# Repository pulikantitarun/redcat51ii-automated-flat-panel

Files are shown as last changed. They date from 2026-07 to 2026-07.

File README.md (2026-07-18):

# RedCat 51 II Automated Flat Panel — Revision C

A servo-driven flat panel / dust cover for the William Optics RedCat 51 II,
commanded from an ASIAIR dew-heater port.

---

## Read this before anything else

Rev B was described as fabrication-ready. It was not. It had a firmware loop
that would hold a stalled 20 kg servo at ~2.7 A indefinitely, an ASIAIR input
that could not physically work, four disconnected bodies in an STL, and not one
copper zone on a 4-layer board carrying two switching regulators. It also had
"0 DRC violations", which is exactly why that number should never have
reassured anyone.

**Rev C is not fabrication-ready either.** It is *correct as far as it has been
checked*, and it now tells you loudly where the checking stops. The difference
between Rev B and Rev C is not that Rev C is finished — it is that Rev C
asserts its own assumptions instead of hiding them.

### Status by subsystem

| Subsystem | State | Verified how |
|---|---|---|
| Mechanical | **Verified** | 19 numeric clearance assertions pass; all 10 meshes single-body and watertight; assembly STEP builds in one shared coordinate frame |
| Firmware | **Reviewed, not run** | No ESP32 toolchain was available; not compiled, not flashed, not measured |
| PCB netlist & stackup | **Asserted** | 36 netlist/stackup assertions pass (`verify_board.py`) |
| PCB routing | **Not done** | Signals unrouted; needs the freerouting round-trip + manual widening |
| PCB schematic / ERC | **Does not exist** | ← the single biggest remaining risk |

---

## The four numbers you must measure

Everything in the mechanical model derives from these. Each has a cheap coupon
to check it. Print the coupons first — they are minutes of filament, and every
one of them protects hours of it.

| # | Parameter | Default | Coupon | What happens if it's wrong |
|---|---|---|---|---|
| 1 | `SCOPE_DIAMETER` | 80.0 mm | `01-diameter-fit-gauge` | Clamp won't fit, or won't grip |
| 2 | `SERVO_SHAFT_OFFSET` | 10.0 mm | `09-servo-shaft-gauge` | Closed panel sits 7–13 mm off the optical axis |
| 3 | `SERVO_EAR_TO_TOP` | 10.0 mm | `09-servo-shaft-gauge` | Tray fouls the servo, or floats above the horn |
| 4 | `DC_JACK_AXIS_Z` | 4.7 mm | `10-connector-wall-coupon` | Barrel plugs don't line up with their holes |

The 80 mm default deserves special suspicion: William Optics quote
"228 × 80 mm with the retracted dew shield". That is a *marketing envelope
figure*, not a measurement of the surface this clamp grips. Measure it.

**A fifth measurement, electrical, is just as important — see below.**

---

## The ASIAIR ground question — measure this before you build the board

Rev C replaces Rev B's opto-isolator with a plain resistive divider into an
ADC. That is the right call (see *Firmware* below), but it costs you the
galvanic isolation, and it therefore **assumes the ASIAIR switches the HIGH
side of its dew ports** — i.e. that the port's negative terminal is common with
the ASIAIR's own 12 V input negative.

All the indirect evidence says it does. People run grounded 12 V→5 V buck
converters off these ports, feeding USB devices that plug straight back into
the ASIAIR, which would be a dead short across a low-side switch. And a
multimeter inline reads ~6 V average at the 50 % slider position, which is what
a high-side switch with a grounded return looks like.

But I have not put a meter on one, and neither should you take my word for it:

> **Check continuity between the ASIAIR dew port's barrel SLEEVE and the
> ASIAIR's power input NEGATIVE terminal.**
> - Near 0 Ω → common ground. Build as drawn.
> - Anything else → **stop.** Do not fit R19. The front end needs rethinking
>   and I'd want to see the measurement before redesigning it.

Thirty seconds with a multimeter, before you spend money.

---

## What changed, and why

### Mechanical — `mechanical/generate_parts.py`

Rev B built every part in its own private coordinate system and never
assembled them. That is how all of the following escaped:

- **The enclosure was built centred on z=0 but every cut-out was placed as if
  the floor were z=0.** The connector openings sat ~14 mm too high and breached
  the top rim.
- **The four PCB standoffs floated in mid-air.** They were extruded z=0..7
  while the cavity floor sat at z=−11.5. The STL contained five disconnected
  bodies. A slicer would have printed four little pillars lying on the bed.
- **The tray pivot assumed the servo's output shaft is at the centre of its
  body.** It is not — a standard 40 mm servo has its shaft offset ~10 mm. The
  closed panel would have sat 7–13 mm off the optical axis.
- **The servo platform met the clamp with a ~1 mm sliver of overlap**, no
  gussets, no fillets.
- **The limit-switch bracket's base and upright met on a single plane with zero
  overlap** — a degenerate union that exports a non-watertight mesh.

Rev C builds every part in **one shared scope coordinate frame**, asserts the
clearances numerically, and exports an assembly STEP so the next mistake of
this class is visible instead of latent.

Also new in Rev C:

- **The lid is screwed, not friction-fit.** This box lives outdoors, upside
  down, in dew, on a moving mount. Four M3 corner bosses with heat-set inserts,
  outboard of the cavity so they cost no internal volume. The lid's spigot lip
  is notched around them.
- **Strap ears.** The box now has somewhere to attach. Thread a hook-and-loop
  strap down through one ear, under the dovetail bar, up through the other.
  **Hang it off the dovetail, not the dew shield** — the shield is a slip joint
  and it will happily let go of an 80 mm tube.

Run it:

```bash
cd mechanical && python3 generate_parts.py
```

It prints 19 clearance assertions and exits non-zero if any fail. All 10 STLs
are single-body and watertight; verify with the trimesh snippet in
`docs/verification.md` if you want to confirm that yourself rather than trust
this file.

### Firmware — `firmware/redcat_flat_panel/`

**1. The ASIAIR input is no longer a duty-cycle measurement.** Rev B called
`pulseIn()` on an opto to recover the ASIAIR's PWM duty. That cannot work on an
ASIAIR Plus:

- The Plus **capacitively filters** its power outputs. Rev B's opto drew ~4.9 mA
  through a 2.2 k resistor — nowhere near enough to discharge that filter inside
  a 20 ms period. The port never left 12 V, so **every slider position read as
  100 %**.
- The port period is 20 ms and Rev B's `pulseIn` timeout was 30 ms. A missed
  edge returned 0 → "command 0" → **the flap flings open in the middle of a
  flat sequence.**

Rev C stops fighting the filter and uses it: it loads the port properly (470 Ω,
1 W) and measures the **average voltage** on ADC1. The same filtering that
destroys duty-sniffing is what makes the average track the slider — 50 % reads
~6 V, 100 % reads ~12 V.

**2. A failed move no longer retries forever.** Rev B's `moveFlap()` set
`isClosed = false` on timeout *regardless of which direction it was moving*. So
a jammed flap reported "open", the next loop pass commanded "close" again ~50 ms
later, and it did that forever — holding a stalled DS3218 at ~2.7 A until
something gave up. Rev C latches a **FAULT** after 3 bounded attempts, detaches
the servo between every attempt, and refuses to move again until a human holds
the button for 2 s.

**3. The move is non-blocking.** Rev B blocked inside `moveFlap()` for up to 5 s
with the button dead.

**4. The ASIAIR boot transient is handled.** Every ASIAIR drives all power ports
to FULL for a few seconds at boot before loading its saved settings. Rev B read
that as "100 % — close and light up". Rev C ignores the input until it has been
stable for 6 s.

**5. Thresholds no longer collide.** Rev B used 3 % / 8 % boundaries when the
ASIAIR slider's minimum non-zero step is **5 %**, with no hysteresis — a reading
sitting on a boundary would dither the flap. Rev C works in **port volts**
(what the board can actually observe) with 0.3 V of hysteresis at every
boundary.

**6. It does not move on boot.** Rev B blindly drove to OPEN in `setup()`,
slamming the flap against its stop every time the ASIAIR's 12 V rail browned out
on a mount slew. Rev C adopts whatever state the limit switches report.

> **This firmware has not been compiled.** There was no ESP32 toolchain
> available in the environment it was written in. Expect to fix at least a
> typo. Read it before you flash it.

**Calibration:** if the panel lights at the wrong slider position, put a
voltmeter on the ASIAIR port at 100 %, set `PORT_FULL_V` to what you actually
read (a "12 V" supply is usually 12.2–13.8 V), and reflash. Nothing else needs
touching.

### PCB — `pcb/source/generate_board.py`

**1. Copper zones.** Rev B had **none** — zero zones, zero G36 fill records in
every gerber, on a 4-layer board with a 4 A switcher. GND was 129 individual
tracks totalling ~500 mm.

Rev C makes **both inner layers solid GND** and pours GND on F.Cu/B.Cu, with
124 stitching vias. Every switching node now has an unbroken return directly
beneath it.

Why two ground planes rather than GND + a split power plane: the Rev B
placement interleaves +12V, +6V and +3V3 across the same X range, so **no
rectangular power split is possible without re-placing every part**. SIG/GND/
GND/SIG is the correct stackup for *this* placement, costs nothing, spreads
regulator heat, and removes any chance of a return path crossing a plane split.
+12V and +6V remain wide tracks, as they were in Rev B — but Rev B's actual
defect was that *GND* had no plane, and that is now fixed twice over.

**2. USBLC6-2SC6 net assignment fixed.** Pins 1 and 6 are one internal node;
3 and 4 are another. Rev B straddled the 22 Ω series resistors across them,
**shorting both out**. DRC was perfectly happy.

**3. J3 re-pinned to GND / V+ / SIG.** Rev B wired 6V / GND / SIG, which lands
6 V on the servo lead's black wire whichever way round you plug it in.

**4. Q1's gate is no longer tied straight to GND.** Vgs was the full rail. While
D1 clamps a surge it would have exceeded the AO4407A's ±20 V limit and destroyed
the FET. Now 100 k to GND plus a 10 V zener gate-to-source.

**5. D1 SMBJ18A → SMBJ14A.** An 18 V standoff part clamps at ~29 V — above the
AO4407A's 30 V Vds rating with no margin. 14 V standoff clamps at ~23 V.

**6. F1 3 A → 4 A.** A 3 A PTC derates to ~2.4 A hold in a sealed box, below the
DS3218's 2.7 A stall. It would have nuisance-tripped mid-sequence.

**7. Buck input capacitance raised.** A 10 µF 25 V 0805 X5R at 12 V DC bias
derates to ~4–5 µF; that was the *entire* input reservoir for a 4 A regulator.
Now 2× 10 µF 1210 plus 100 nF per regulator.

**8. Minimum drill 0.2 → 0.3 mm**, above every fab's surcharge threshold.

Run it:

```bash
cd pcb/source
python3 generate_board.py     # places parts, nets, zones, stitching vias
python3 verify_board.py       # 36 netlist/stackup assertions
python3 generate_bom.py       # BOM generated FROM the board, so it can't drift
```

---

## What is still missing — the honest list

1. **There is no schematic, and therefore there has been no ERC.** This is the
   biggest risk in the project. A DRC pass against a hand-typed netlist only
   proves the copper matches what you typed; it cannot tell you the netlist
   itself is wrong. That is *precisely* how the USBLC6 short and the servo
   header pinout survived Rev B's "0 DRC violations". `verify_board.py` raises
   the floor but it is not ERC. **Draw the schematic before you spend money.**

2. **Signals are not routed.** `generate_board.py` emits placement, nets and
   pours. The Rev B flow still applies — `export_dsn.py` → freerouting →
   `import_ses.py` → manually widen the +12 V / +6 V paths — **except that GND
   must no longer be handed to the autorouter.** It lives on the planes now.

3. **Zones are defined but not filled in the saved file.** pcbnew's `ZONE_FILLER`
   segfaults when driven from standalone Python on KiCad 7 (verified: it does so
   even under a wx app and a virtual X display). The zones are defined, netted
   and layered correctly — but **KiCad plots gerbers from the *stored* fill.**
   Open the board in pcbnew, press **B**, run DRC, *then* plot. Plotting without
   filling gives you planeless gerbers — the exact Rev B failure, wearing a
   Rev C label.

4. **The firmware has never been compiled or run.**

5. **The board was generated here against KiCad 7**, because that is what was
   installable; you built Rev B on KiCad 10. The script is version-tolerant now
   (it searches for the footprint libraries instead of hard-coding
   `C:\Users\tarun\...`, and accepts alternate footprint names), but **re-run it
   on your KiCad 10** and use that output. One visible symptom: the BOM here
   lists `SW_Push_1P1T_NO_CK_KMR2` for SW1–3 because KiCad 7's library lacks the
   TL3301; KiCad 10 will pick the TL3301 as intended.

6. **The 6 V rail is still track-routed at up to 2.7 A.** Widen it by hand after
   routing. 3 mm on 1 oz copper is roughly 3 A.

---

## Suggested order of work

1. Multimeter on the ASIAIR dew port ground. **30 seconds. Do it first.**
2. Print `01`, `09`, `10`. Measure the four parameters. Update the constants.
3. Re-run `generate_parts.py`. Confirm 19/19 assertions still pass.
4. Print `02`–`08`. Assemble dry, no electronics.
5. Draw the schematic in KiCad from `generate_board.py`. Run ERC. **Expect it to
   find something.**
6. Route, fill, DRC, then fab.
7. Bench the firmware on the bare board with a current-limited supply and a
   servo you don't love, before it ever goes near the RedCat.

---

## Layout

```
mechanical/
  generate_parts.py          one coordinate frame, 19 assertions, 10 parts
  00-ASSEMBLY.step           everything placed in the scope frame
  01..10-*.stl/.step         printable parts + verification coupons
firmware/
  redcat_flat_panel/redcat_flat_panel.ino
pcb/
  BOM_RevC.csv               generated from the board
  source/
    generate_board.py        placement, nets, zones, stitching
    verify_board.py          36 netlist/stackup assertions
    generate_bom.py
```

## License

Copyright (C) 2026 pulikantitarun

This project - the mechanical design files, firmware, PCB design, and documentation - is licensed under the **GNU Affero General Public License, version 3 or later (AGPL-3.0-or-later)**. See [LICENSE](LICENSE) for the full text.

You are free to use, study, share, and modify this work, including as forks. In return, the copyleft terms require that if you distribute a modified version - or run a modified version to offer a service over a network - you make your modified source available under this same license. Forks and derivatives must remain AGPL-3.0.

Note on scope: AGPL is a software license. It fits the firmware and the generator scripts cleanly; the mechanical CAD/STL and PCB design files are released under it here as copyrightable design works. If you later want a copyleft written specifically for physical hardware, CERN-OHL-S is the usual companion, but AGPL across the whole repository is a common, valid choice and satisfies the goal that forks stay open. This paragraph is not legal advice.

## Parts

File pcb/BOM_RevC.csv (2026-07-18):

Comment | Designator | Footprint | Quantity
1uF | C1 | C_0603_1608Metric | 1
470uF 25V | C2 | CP_Elec_10x10.5 | 1
100nF | C3,C8,C13,C15,C16,C17 | C_0603_1608Metric | 6
10uF 25V | C4B,C4,C9 | C_1210_3225Metric | 3
22uF 10V | C5,C6,C10,C11 | C_0805_2012Metric | 4
470uF 10V | C7 | CP_Elec_8x10.5 | 1
10uF | C12,C14 | C_0805_2012Metric | 2
SMBJ14A | D1 | D_SMB | 1
MMSZ5226B 3V3 | D2 | D_SOD-123 | 1
MMSZ5240B 10V | D3 | D_SOD-123 | 1
4A 16V PTC | F1 | Fuse_1812_4532Metric | 1
MAIN 12V DC5521 | J1 | BarrelJack_CUI_PJ-102AH_Horizontal | 1
ASIAIR PWM DC5521 | J2 | BarrelJack_CUI_PJ-102AH_Horizontal | 1
SERVO GND 6V SIG | J3 | PinHeader_1x03_P2.54mm_Vertical | 1
LED PANEL | J4 | JST_XH_B2B-XH-A_1x02_P2.50mm_Vertical | 1
OPEN LIMIT | J5 | JST_XH_B2B-XH-A_1x02_P2.50mm_Vertical | 1
CLOSED LIMIT | J6 | JST_XH_B2B-XH-A_1x02_P2.50mm_Vertical | 1
EXT MANUAL | J7 | JST_XH_B2B-XH-A_1x02_P2.50mm_Vertical | 1
USB-C PROGRAM | J8 | USB_C_Receptacle_GCT_USB4105-xx-A_16P_TopMnt_Horizontal | 1
3.3uH 6.5A | L1 | L_6.3x6.3_H3 | 1
4.7uH 3A | L2 | L_6.3x6.3_H3 | 1
STATUS BLUE | LED1 | LED_0603_1608Metric | 1
POWER GREEN | LED2 | LED_0603_1608Metric | 1
AO4407A | Q1 | SO-8_3.9x4.9mm_P1.27mm | 1
AO3400A | Q2 | SOT-23 | 1
5.1k | R1,R2 | R_0603_1608Metric | 2
22R | R3,R4 | R_0603_1608Metric | 2
10k | R5,R6,R10,R12,R13,R14,R15 | R_0603_1608Metric | 7
64.9k 1% | R7 | R_0603_1608Metric | 1
10k 1% | R8 | R_0603_1608Metric | 1
470R 1W | R9 | R_2512_6332Metric | 1
100R | R11 | R_0603_1608Metric | 1
1k | R16,R17 | R_0603_1608Metric | 2
100k | R18,R21 | R_0603_1608Metric | 2
0R | R19 | R_1206_3216Metric | 1
3k3 | R20 | R_0603_1608Metric | 1
RESET | SW1 | SW_Push_1P1T_NO_CK_KMR2 | 1
BOOT | SW2 | SW_Push_1P1T_NO_CK_KMR2 | 1
MANUAL | SW3 | SW_Push_1P1T_NO_CK_KMR2 | 1
ESP32-S3-WROOM-1-N8R8 | U1 | ESP32-S3-WROOM-1 | 1
USBLC6-2SC6 | U2 | SOT-23-6 | 1
AP62401WU-7 | U3 | TSOT-23-6 | 1
AP63203WU-7 | U4 | TSOT-23-6 | 1

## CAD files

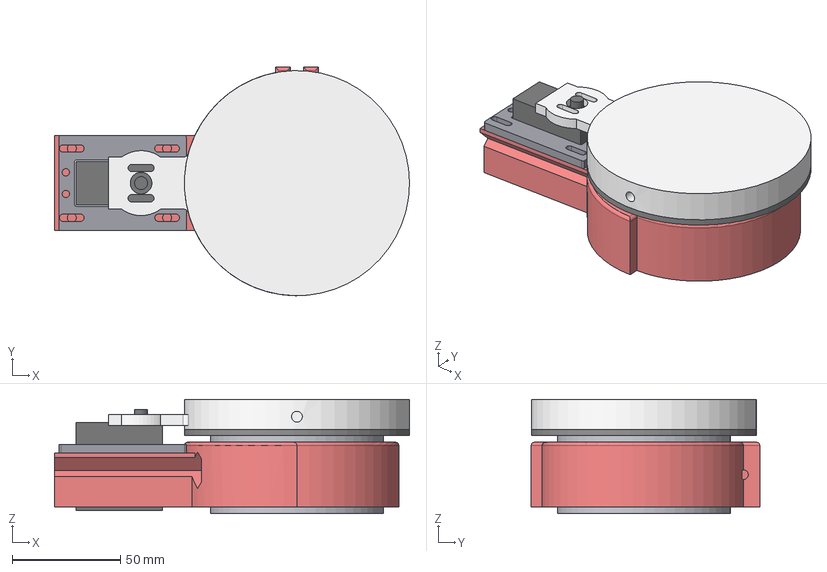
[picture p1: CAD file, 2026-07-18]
mechanical/00-ASSEMBLY.step
164.0 x 105.6 x 52.8 mm
clamp
servo_plate
tray
retainer
servo_envelope
dew_shield_envelope

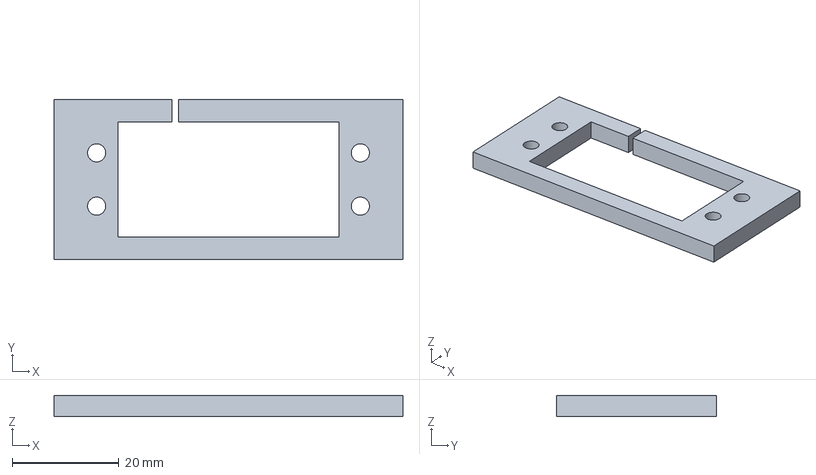
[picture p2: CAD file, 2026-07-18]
mechanical/09-servo-shaft-gauge.step
65.5 x 30.0 x 4.00 mm

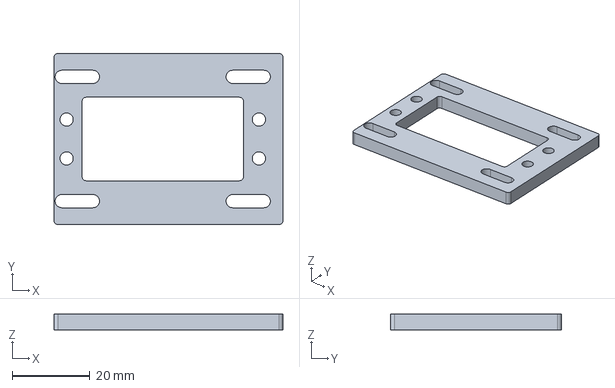
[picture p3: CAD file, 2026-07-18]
mechanical/03-ds3218-servo-plate.step
59.0 x 44.0 x 4.00 mm

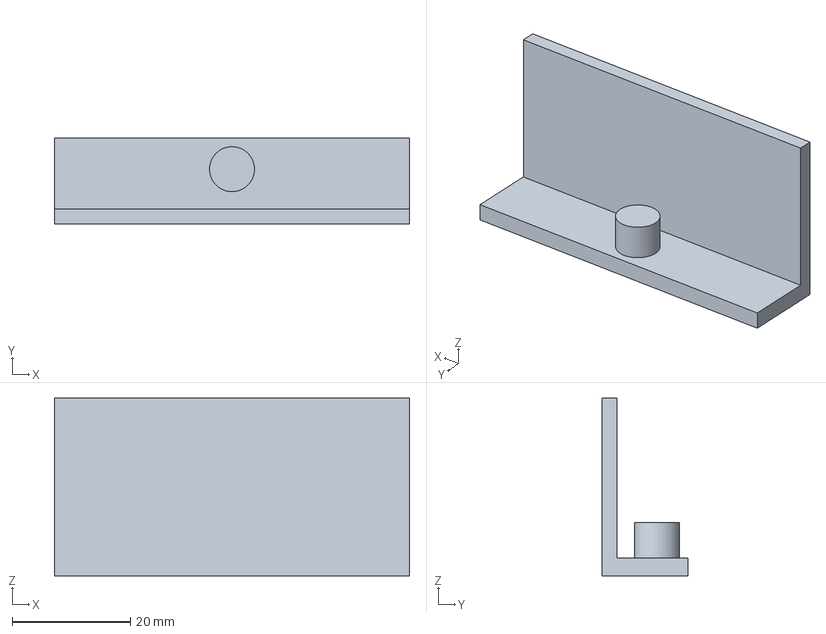
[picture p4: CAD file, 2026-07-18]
mechanical/10-connector-wall-coupon.step
60.0 x 14.6 x 30.0 mm

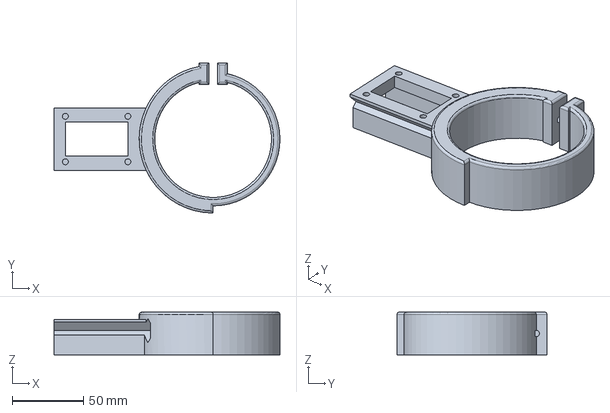
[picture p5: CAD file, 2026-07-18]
mechanical/02-scope-clamp.step
159.0 x 105.6 x 30.0 mm

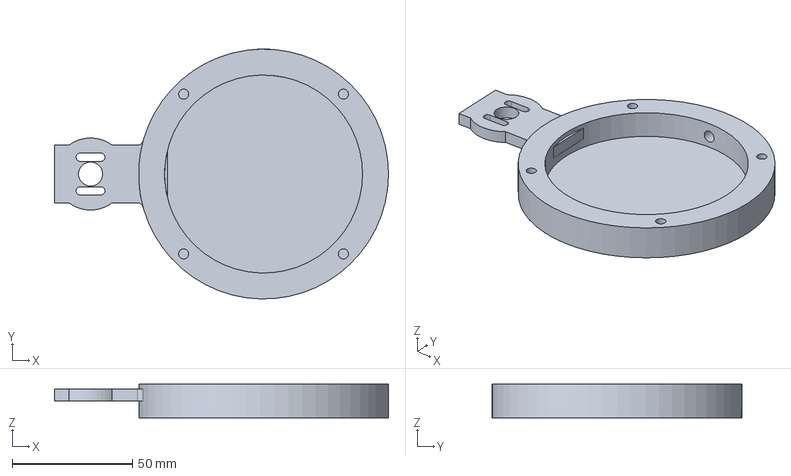
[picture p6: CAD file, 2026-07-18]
mechanical/04-flat-panel-tray.step
139.0 x 104.0 x 14.0 mm

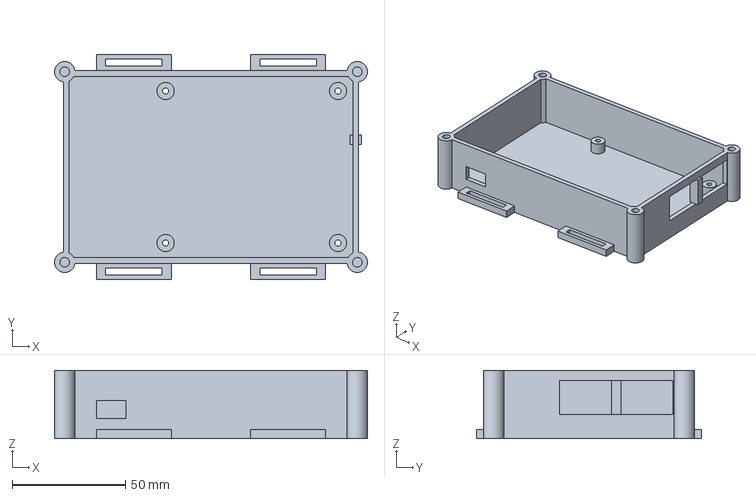
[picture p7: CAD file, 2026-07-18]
mechanical/06-electronics-enclosure-base.step
138.0 x 99.2 x 30.0 mm

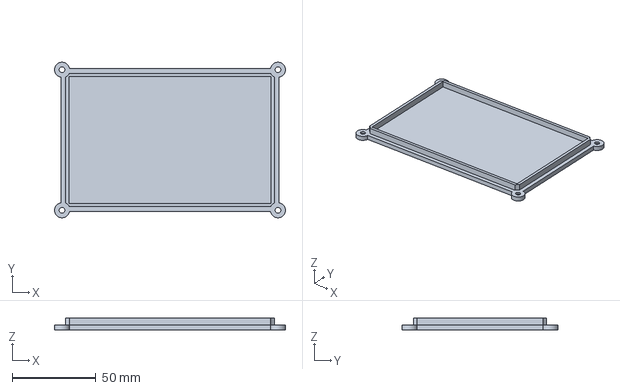
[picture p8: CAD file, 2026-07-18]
mechanical/07-electronics-enclosure-lid.step
138.0 x 93.0 x 7.00 mm

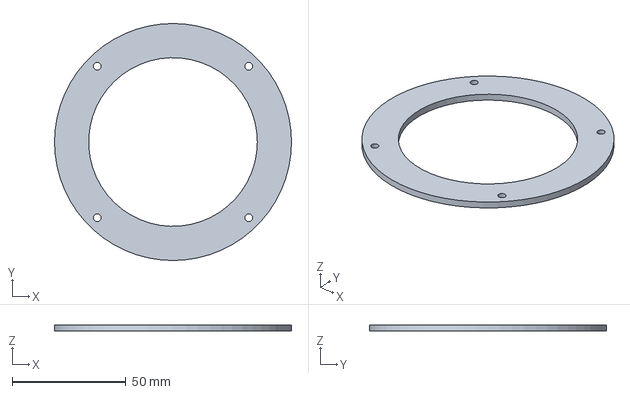
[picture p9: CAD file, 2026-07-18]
mechanical/05-diffuser-retaining-ring.step
104.0 x 104.0 x 2.80 mm

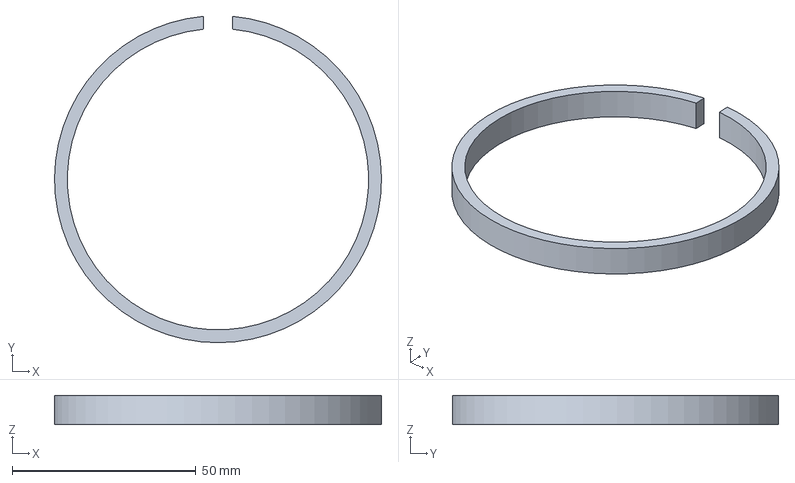
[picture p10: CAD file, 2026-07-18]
mechanical/01-diameter-fit-gauge.step
89.1 x 88.9 x 8.00 mm

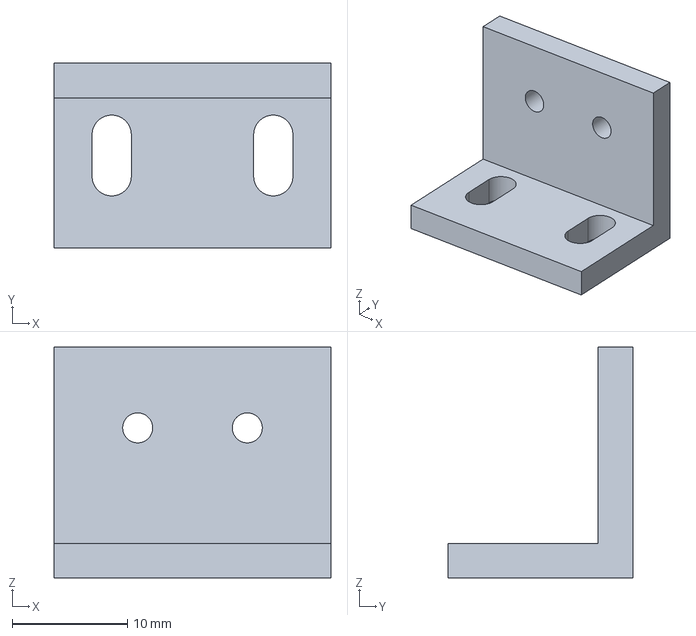
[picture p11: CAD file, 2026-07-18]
mechanical/08-limit-switch-bracket-print-two.step
24.0 x 16.0 x 20.0 mm

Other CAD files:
mechanical/01-diameter-fit-gauge.stl
mechanical/02-scope-clamp.stl
mechanical/03-ds3218-servo-plate.stl
mechanical/04-flat-panel-tray.stl
mechanical/05-diffuser-retaining-ring.stl
mechanical/06-electronics-enclosure-base.stl
mechanical/07-electronics-enclosure-lid.stl
mechanical/08-limit-switch-bracket-print-two.stl
mechanical/09-servo-shaft-gauge.stl
mechanical/10-connector-wall-coupon.stl

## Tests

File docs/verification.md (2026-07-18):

# Verifying Rev C yourself

Rev B's problem was not that it was wrong. Everything is wrong at some point.
Rev B's problem was that nothing in it could tell you it was wrong — the
generators had no assertions, the parts were never assembled, and the one number
that *did* get reported ("0 DRC violations") was measuring something that had no
bearing on whether the design worked.

So: don't take Rev C's word for it either. Here is how to re-check every claim
in the README from scratch.

---

## 1. Mechanical clearances

```bash
cd mechanical && python3 generate_parts.py
```

Prints 19 assertions and returns a non-zero exit code if any fail. Requires
`cadquery`.

To confirm they're real rather than decorative, break one on purpose:

```python
# in generate_parts.py, temporarily:
PIVOT_R = 55.0          # was 72.0
```

Re-run. You should see the servo body clearance go negative and the run fail.
If it doesn't, the assertion isn't testing what it claims.

## 2. Mesh integrity

The Rev B enclosure base exported **five disconnected bodies** and nobody
noticed, because nothing looked. This is the check that would have caught it:

```bash
cd mechanical
python3 -c "
import trimesh, glob
for f in sorted(glob.glob('*.stl')):
    m = trimesh.load(f, force='mesh')
    print('%-42s tris=%-6d bodies=%-2d watertight=%s' % (
        f, len(m.faces), len(m.split(only_watertight=False)), m.is_watertight))
"
```

Every line must read `bodies=1 watertight=True`. Anything else is a part that
will slice into nonsense.

Expected:

```
01-diameter-fit-gauge.stl                  tris=984    bodies=1  watertight=True
02-scope-clamp.stl                         tris=27994  bodies=1  watertight=True
03-ds3218-servo-plate.stl                  tris=5152   bodies=1  watertight=True
04-flat-panel-tray.stl                     tris=5776   bodies=1  watertight=True
05-diffuser-retaining-ring.stl             tris=3040   bodies=1  watertight=True
06-electronics-enclosure-base.stl          tris=7944   bodies=1  watertight=True
07-electronics-enclosure-lid.stl           tris=5724   bodies=1  watertight=True
08-limit-switch-bracket-print-two.stl      tris=2068   bodies=1  watertight=True
09-servo-shaft-gauge.stl                   tris=2076   bodies=1  watertight=True
10-connector-wall-coupon.stl               tris=524    bodies=1  watertight=True
```

## 3. Assembly

Open `mechanical/00-ASSEMBLY.step` in any CAD viewer. It contains the clamp,
servo plate, tray, retaining ring, a servo envelope block and a dew-shield
cylinder — all placed in the shared scope frame.

Look for the thing the numbers can't tell you: does the closed panel sit on the
optical axis, and does the open panel get out of the light path? The assertions
check both, but eyes are better at "that looks wrong" than any assertion is.

## 4. PCB netlist

```bash
cd pcb/source
python3 generate_board.py
python3 verify_board.py
```

36 assertions. These are the ones that would have failed on Rev B while DRC
reported zero violations:

- `U2 pins 1 and 6 share a net` — Rev B shorted R3 out
- `U2 pins 3 and 4 share a net` — Rev B shorted R4 out
- `J3 pin 1 = GND` — Rev B had +6 V there
- `Q1 gate is not hard-tied to GND` — Rev B tied it
- `F.Cu / In1.Cu / In2.Cu / B.Cu has at least one copper zone` — Rev B had none, anywhere

Same trick as before — break one deliberately and confirm the check catches it:

```python
# in generate_board.py, temporarily:
setnets(j3, {"1": "+6V", "2": "GND", "3": "SERVO_SIG"})   # the Rev B pinout
```

`verify_board.py` must fail on `J3 pin 1 = GND`.

## 5. The gerber check Rev B needed

After routing and filling, before you upload anything, count the fill records:

```bash
cd <gerber dir>
for f in *.gbr *.g?? ; do
  printf '%-40s G36 fills: %s\n' "$f" "$(grep -c '^G36' "$f" 2>/dev/null)"
done
```

The two inner layers must show a healthy non-zero count. Rev B's showed **zero
on every single layer** — that one command, run once, would have caught the
entire copper problem before it reached a fab queue.

---

## What none of this proves

- **That the circuit is correct.** There is no schematic and no ERC. Every
  assertion in `verify_board.py` is a thing I thought to check. The bug that
  gets you is the one nobody thought to check — which is the entire argument for
  drawing the schematic and letting ERC look at it with fresh eyes.
- **That the firmware runs.** It has never been compiled.
- **That the four measured parameters are right.** Only a caliper proves that.
- **That the ASIAIR port is high-side switched.** Only a multimeter proves that.

The point of Rev C isn't that it's right. It's that when it's wrong, something
says so.

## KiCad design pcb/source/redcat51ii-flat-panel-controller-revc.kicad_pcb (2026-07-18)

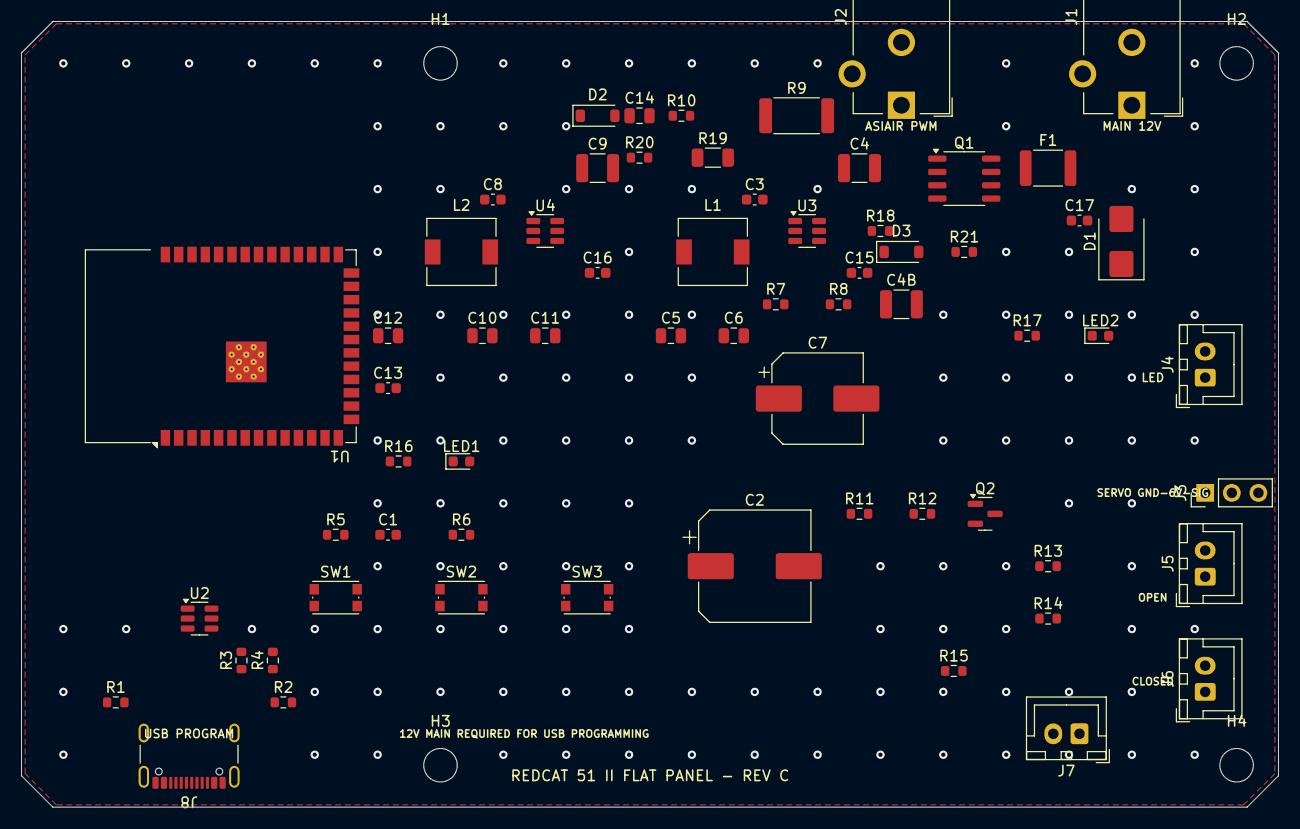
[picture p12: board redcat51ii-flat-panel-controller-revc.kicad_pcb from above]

Board: 4 copper layers, 120.0 x 75.0 mm, 68 parts (0 on the bottom side), 35 nets, no tracks yet.

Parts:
C1: 1uF; C_0603_1608Metric
C2: 470uF 25V; CP_Elec_10x10.5
C3, C8, C13, C15, C16, C17: 100nF; C_0603_1608Metric
C4, C4B, C9: 10uF 25V; C_1210_3225Metric
C5, C6, C10, C11: 22uF 10V; C_0805_2012Metric
C7: 470uF 10V; CP_Elec_8x10.5
C12, C14: 10uF; C_0805_2012Metric
D1: SMBJ14A; D_SMB
D2: MMSZ5226B 3V3; D_SOD-123
D3: MMSZ5240B 10V; D_SOD-123
F1: 4A 16V PTC; Fuse_1812_4532Metric
H1, H2, H3, H4: M3; MountingHole_3.2mm_M3
J1: MAIN 12V DC5521; BarrelJack_CUI_PJ-102AH_Horizontal
J2: ASIAIR PWM DC5521; BarrelJack_CUI_PJ-102AH_Horizontal
J3: SERVO GND 6V SIG; PinHeader_1x03_P2.54mm_Vertical
J4: LED PANEL; JST_XH_B2B-XH-A_1x02_P2.50mm_Vertical
J5: OPEN LIMIT; JST_XH_B2B-XH-A_1x02_P2.50mm_Vertical
J6: CLOSED LIMIT; JST_XH_B2B-XH-A_1x02_P2.50mm_Vertical
J7: EXT MANUAL; JST_XH_B2B-XH-A_1x02_P2.50mm_Vertical
J8: USB-C PROGRAM; USB_C_Receptacle_GCT_USB4105-xx-A_16P_TopMnt_Horizontal
L1: 3.3uH 6.5A; L_6.3x6.3_H3
L2: 4.7uH 3A; L_6.3x6.3_H3
LED1: STATUS BLUE; LED_0603_1608Metric
LED2: POWER GREEN; LED_0603_1608Metric
Q1: AO4407A; SO-8_3.9x4.9mm_P1.27mm
Q2: AO3400A; SOT-23
R1, R2: 5.1k; R_0603_1608Metric
R3, R4: 22R; R_0603_1608Metric
R5, R6, R10, R12, R13, R14, R15: 10k; R_0603_1608Metric
R7: 64.9k 1%; R_0603_1608Metric
R8: 10k 1%; R_0603_1608Metric
R9: 470R 1W; R_2512_6332Metric
R11: 100R; R_0603_1608Metric
R16, R17: 1k; R_0603_1608Metric
R18, R21: 100k; R_0603_1608Metric
R19: 0R; R_1206_3216Metric
R20: 3k3; R_0603_1608Metric
SW1: RESET; SW_Push_1P1T_NO_CK_KMR2
SW2: BOOT; SW_Push_1P1T_NO_CK_KMR2
SW3: MANUAL; SW_Push_1P1T_NO_CK_KMR2
U1: ESP32-S3-WROOM-1-N8R8; ESP32-S3-WROOM-1
U2: USBLC6-2SC6; SOT-23-6
U3: AP62401WU-7; TSOT-23-6
U4: AP63203WU-7; TSOT-23-6

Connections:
+3V3: C10.1, C11.1, C12.1, C13.1, L2.2, R5.1, R6.1, R13.1, R14.1, R15.1, R17.1, U1.2, U4.4
+6V: C5.1, C6.1, C7.1, J3.2, L1.2, R7.1
+12V: C2.1, C4.1, C4B.1, C9.1, C15.1, C16.1, D1.1, D3.1, J4.1, Q1.1, Q1.2, Q1.3, R18.1, U3.3, U4.3, U4.5
+12V_FUSED: F1.2, Q1.5, Q1.6, Q1.7, Q1.8
+12V_RAW: C17.1, F1.1, J1.1
ASIAIR+: J2.1, R9.1, R10.1
ASIAIR-: J2.2, J2.3, R9.2, R19.1
ASIAIR_SIG: C14.1, D2.1, R10.2, R20.1, U1.4
BOOT: R6.2, SW2.1, U1.27
BST3: C8.1, U4.6
BST6: C3.1, U3.6
BUTTON_SIG: J7.1, R15.2, SW3.1, U1.17
CC1: J8.A5, R1.1
CC2: J8.B5, R2.1
CLOSED_SIG: J6.1, R14.2, U1.7
EN: C1.1, R5.2, SW1.1, U1.3
EN6: R18.2, U3.5
FB6: R7.2, R8.1, U3.4
GATE12: D3.2, Q1.4, R21.1
GND: C1.2, C2.2, C4.2, C4B.2, C5.2, C6.2, C7.2, C9.2, C10.2, C11.2, C12.2, C13.2, C14.2, C15.2, C16.2, C17.2, D1.2, D2.2, J1.2, J1.3, J3.1, J5.2, J6.2, J7.2, J8.A1, J8.A12, J8.B1, J8.B12, J8.S1, LED1.1, LED2.1, Q2.2, R1.2, R2.2, R8.2, R12.2, R19.2, R20.2, R21.2, SW1.2, SW2.2, SW3.2, U1.1, U1.40, U1.41, U2.2, U3.1, U4.1
LED_GATE: Q2.1, R11.2, R12.1
LED_NEG: J4.2, Q2.3
LED_PWM: R11.1, U1.5
OPEN_SIG: J5.1, R13.2, U1.6
PWR_LED: LED2.2, R17.2
SERVO_SIG: J3.3, U1.11
STATUS_A: LED1.2, R16.2
STATUS_LED: R16.1, U1.8
SW3: C8.2, L2.1, U4.2
SW6: C3.2, L1.1, U3.2
USB_D+: R3.2, U1.14
USB_D+_J: J8.A6, J8.B6, R3.1, U2.1, U2.6
USB_D-: R4.2, U1.13
USB_D-_J: J8.A7, J8.B7, R4.1, U2.3, U2.4
USB_VBUS: J8.A4, J8.A9, J8.B4, J8.B9, U2.5

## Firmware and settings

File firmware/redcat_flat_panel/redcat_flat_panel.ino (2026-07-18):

// ===========================================================================
// RedCat 51 II automated flat panel - Revision C firmware
// ESP32-S3-WROOM-1, Arduino-ESP32 core 3.x, ESP32Servo library
//
// WHAT CHANGED FROM REV B, AND WHY
// ---------------------------------
// 1. THE ASIAIR INPUT IS NO LONGER A DUTY-CYCLE MEASUREMENT.
//    Rev B called pulseIn() on an opto-isolator to recover the ASIAIR's PWM
//    duty. That cannot work on an ASIAIR Plus:
//      - the Plus capacitively filters its power outputs, so with the ~5 mA
//        the Rev B opto drew, the port never falls away from 12 V and every
//        slider position reads as 100 %;
//      - the port period is 20 ms, and Rev B's pulseIn timeout was 30 ms, so
//        a missed edge returned 0 -> "command 0" -> the flap flung open in
//        the middle of a flat sequence.
//    Rev C loads the port properly and measures its AVERAGE VOLTAGE on an
//    ADC. The same filtering that destroys duty-sniffing is exactly what makes
//    the average track the slider: 50 % reads ~6 V, 100 % reads ~12 V.
//
// 2. A FAILED MOVE NO LONGER RETRIES FOREVER.
//    Rev B's moveFlap() set isClosed=false on timeout regardless of which way
//    it was moving. A jammed flap therefore reported "open", so the next loop
//    pass commanded "close" again, ~50 ms later, forever - holding a stalled
//    DS3218 at ~2.7 A until something gave up. Rev C latches a FAULT after
//    MAX_MOVE_ATTEMPTS, detaches the servo, and refuses to move again until a
//    human clears it.
//
// 3. THE MOVE IS NON-BLOCKING. Rev B blocked inside moveFlap() for up to 5 s
//    with interrupts servicing nothing, so the button was dead during a move.
//
// 4. THE ASIAIR BOOT TRANSIENT IS HANDLED. Every ASIAIR drives all power
//    ports to FULL for a few seconds at boot, before it loads its saved port
//    settings. Rev B would have read that as "100 % - close and light up".
//    Rev C ignores the input until it has been stable for SETTLE_MS.
//
// 5. THRESHOLDS NO LONGER COLLIDE. Rev B used 3 % / 8 % boundaries when the
//    ASIAIR slider's minimum non-zero step is 5 %, and had no hysteresis, so
//    a reading sitting on a boundary would dither the flap open/closed.
// ===========================================================================

#include <ESP32Servo.h>

// --------------------------------------------------------------------------
// Pin map - matches the Rev C PCB (unchanged from Rev B; it was correct)
// --------------------------------------------------------------------------
constexpr int PIN_ASIAIR       = 4;   // ADC1_CH3 - divided average of the port
constexpr int PIN_LED          = 5;   // panel MOSFET gate, 20 kHz
constexpr int PIN_OPEN_LIMIT   = 6;   // NO to GND: LOW = at the open stop
constexpr int PIN_CLOSED_LIMIT = 7;   // NO to GND: LOW = at the closed stop
constexpr int PIN_BUTTON       = 9;   // NO to GND
constexpr int PIN_SERVO        = 18;
constexpr int PIN_STATUS       = 15;

// --------------------------------------------------------------------------
// Servo travel
// --------------------------------------------------------------------------
constexpr int OPEN_ANGLE   = 112;
constexpr int CLOSED_ANGLE = 8;

// --------------------------------------------------------------------------
// ASIAIR input scaling
//
// Divider on the board is 10k (top) / 3.3k (bottom), so the ADC sees
//   V_adc = V_port * 3.3 / 13.3 = V_port * 0.2481
// and 12 V at the port -> 2.977 V at the pin, just inside the ESP32-S3's
// ~3.1 V full scale at 12 dB attenuation.
//
// CALIBRATION: if your panel lights at the wrong slider position, put a
// voltmeter on the ASIAIR port at 100 % and set PORT_FULL_V to what you read
// (a "12 V" supply is usually 12.2-13.8 V). Nothing else needs touching.
// --------------------------------------------------------------------------
constexpr float DIVIDER_RATIO = 3.3f / (10.0f + 3.3f);
constexpr float PORT_FULL_V   = 12.0f;

// Command thresholds in PORT VOLTS, not percent - percent is a property of
// the ASIAIR's slider, volts are what this board can actually observe.
// The ASIAIR slider's minimum non-zero position is 5 % (~0.6 V), so "off"
// must sit well below that.
constexpr float V_OPEN_MAX  = 0.80f;  // below this: port off -> park OPEN
constexpr float V_COVER_MAX = 2.80f;  // 0.8-2.8 V: CLOSED, panel dark
constexpr float V_LIGHT_MIN = 3.20f;  // above this: CLOSED, panel lit
constexpr float V_HYST      = 0.30f;  // applied at every boundary

// --------------------------------------------------------------------------
// Timing / limits
// --------------------------------------------------------------------------
constexpr unsigned long MOVE_TIMEOUT_MS  = 4000;  // one attempt
constexpr unsigned long MOVE_REST_MS     = 1500;  // servo OFF between attempts
constexpr int           MAX_MOVE_ATTEMPTS = 3;
constexpr unsigned long LIMIT_DEBOUNCE_MS = 40;
constexpr unsigned long SETTLE_MS        = 6000;  // ASIAIR boot transient
constexpr unsigned long BUTTON_DEBOUNCE_MS = 250;
constexpr unsigned long FAULT_CLEAR_HOLD_MS = 2000;
constexpr unsigned long SAMPLE_INTERVAL_MS = 100;

constexpr int LED_PWM_BITS = 12;
constexpr int LED_PWM_MAX  = (1 << LED_PWM_BITS) - 1;
constexpr int LED_PWM_HZ   = 20000;

// --------------------------------------------------------------------------
// State
// --------------------------------------------------------------------------
enum FlapState : uint8_t { FLAP_UNKNOWN, FLAP_OPEN, FLAP_CLOSED, FLAP_MOVING, FLAP_FAULT };
enum Command   : uint8_t { CMD_OPEN, CMD_COVER, CMD_LIGHT };

Servo flapServo;

FlapState flapState   = FLAP_UNKNOWN;
Command   lastCommand = CMD_OPEN;
bool      manualOverride = false;   // button has taken control from the ASIAIR
bool      manualWantClosed = false;

// move engine
bool          moveActive     = false;
bool          moveWantClosed = false;
int           moveAttempt    = 0;
unsigned long moveStartedMs  = 0;
unsigned long moveRestUntil  = 0;

unsigned long bootMs          = 0;
unsigned long lastSampleMs    = 0;
unsigned long buttonDownMs    = 0;
bool          buttonWasDown   = false;
bool          settled         = false;
float         settleRefV      = 0.0f;
unsigned long settleSinceMs   = 0;

float  ledDuty = 0.0f;
String faultReason = "";

// ===========================================================================
// Panel
// ===========================================================================
// The panel is only ever allowed to light when the cover is CONFIRMED closed.
// An illuminated panel with the cover open points a light source at whatever
// the scope is aimed at, and ruins the sub anyway.
void setLed(float duty) {
  if (flapState != FLAP_CLOSED) duty = 0.0f;
  duty = constrain(duty, 0.0f, 1.0f);
  ledDuty = duty;
  ledcWrite(PIN_LED, (int)(duty * LED_PWM_MAX));
}

// ===========================================================================
// ASIAIR port sensing
// ===========================================================================
// Oversample and take the MEDIAN, then average the middle of the distribution.
// The port is a filtered 20 ms PWM: there is residual ripple, and the ESP32-S3
// SAR ADC is noisy and non-linear near the rails. A median rejects both the
// ripple peaks and the occasional wild sample.
float readPortVolts() {
  constexpr int N = 33;
  uint16_t mv[N];
  for (int i = 0; i < N; i++) {
    mv[i] = analogReadMilliVolts(PIN_ASIAIR);
    delayMicroseconds(600);              // spread across ~20 ms = one period
  }
  // insertion sort - N is tiny
  for (int i = 1; i < N; i++) {
    uint16_t k = mv[i];
    int j = i - 1;
    while (j >= 0 && mv[j] > k) { mv[j + 1] = mv[j]; j--; }
    mv[j + 1] = k;
  }
  // mean of the middle third
  uint32_t acc = 0;
  int lo = N / 3, hi = N - N / 3;
  for (int i = lo; i < hi; i++) acc += mv[i];
  float vAdc = (acc / (float)(hi - lo)) / 1000.0f;
  return vAdc / DIVIDER_RATIO;
}

// Hysteresis: a boundary only counts if we cross it by V_HYST in the
// direction we are not already in.
Command classify(float v, Command prev) {
  float openMax  = V_OPEN_MAX  + (prev == CMD_OPEN  ? V_HYST : 0.0f);
  float coverMax = V_COVER_MAX + (prev == CMD_COVER ? V_HYST : 0.0f);
  float lightMin = V_LIGHT_MIN - (prev == CMD_LIGHT ? V_HYST : 0.0f);

  if (v < openMax)  return CMD_OPEN;
  if (v < coverMax) return CMD_COVER;
  if (v >= lightMin) return CMD_LIGHT;
  return prev == CMD_LIGHT ? CMD_LIGHT : CMD_COVER;  // inside the dead band
}

float brightnessFor(float v) {
  float span = (PORT_FULL_V - 0.5f) - V_LIGHT_MIN;
  if (span <= 0.1f) return 1.0f;
  return constrain((v - V_LIGHT_MIN) / span, 0.0f, 1.0f);
}

// ===========================================================================
// Limit switches
// ===========================================================================
bool limitAsserted(int pin) {
  if (digitalRead(pin) != LOW) return false;
  delay(LIMIT_DEBOUNCE_MS);
  return digitalRead(pin) == LOW;
}

// ===========================================================================
// Move engine - non-blocking, bounded retries, latching fault
// ===========================================================================
void enterFault(const char *why) {
  flapServo.detach();
  moveActive = false;
  flapState  = FLAP_FAULT;
  faultReason = why;
  ledcWrite(PIN_LED, 0);
  ledDuty = 0.0f;
  Serial.printf("[FAULT] %s\n", why);
}

void beginMove(bool wantClosed) {
  if (flapState == FLAP_FAULT) return;
  if (moveActive && moveWantClosed == wantClosed) return;
  ledcWrite(PIN_LED, 0);           // never move a lit panel
  ledDuty = 0.0f;
  moveActive     = true;
  moveWantClosed = wantClosed;
  moveAttempt    = 0;
  moveRestUntil  = 0;
  moveStartedMs  = 0;              // forces attempt 1 to start immediately
  flapState      = FLAP_MOVING;
  Serial.printf("[MOVE] -> %s\n", wantClosed ? "CLOSED" : "OPEN");
}

void serviceMove() {
  if (!moveActive) return;
  unsigned long now = millis();
  if (now < moveRestUntil) return;

  // start an attempt
  if (moveStartedMs == 0) {
    moveAttempt++;
    if (moveAttempt > MAX_MOVE_ATTEMPTS) {
      enterFault(moveWantClosed ? "flap did not reach the CLOSED stop"
                                : "flap did not reach the OPEN stop");
      return;
    }
    flapServo.attach(PIN_SERVO, 500, 2500);
    flapServo.write(moveWantClosed ? CLOSED_ANGLE : OPEN_ANGLE);
    moveStartedMs = now;
    Serial.printf("[MOVE] attempt %d/%d\n", moveAttempt, MAX_MOVE_ATTEMPTS);
    return;
  }

  // arrived?
  int limitPin = moveWantClosed ? PIN_CLOSED_LIMIT : PIN_OPEN_LIMIT;
  if (limitAsserted(limitPin)) {
    delay(120);                    // let it settle onto the stop
    flapServo.detach();            // stop holding torque: no buzz, no heat
    moveActive = false;
    flapState  = moveWantClosed ? FLAP_CLOSED : FLAP_OPEN;
    digitalWrite(PIN_STATUS, flapState == FLAP_CLOSED ? HIGH : LOW);
    Serial.printf("[MOVE] reached %s\n", moveWantClosed ? "CLOSED" : "OPEN");
    return;
  }

  // timed out - back off, de-energise, and try again a bounded number of times
  if (now - moveStartedMs > MOVE_TIMEOUT_MS) {
    flapServo.detach();            // <-- the line Rev B never had
    moveStartedMs = 0;
    moveRestUntil = now + MOVE_REST_MS;
    Serial.printf("[MOVE] attempt %d timed out, resting\n", moveAttempt);
  }
}

// ===========================================================================
// Status LED
//   solid   = closed
//   off     = open
//   slow    = moving
//   fast    = FAULT
// ===========================================================================
void serviceStatusLed() {
  unsigned long t = millis();
  switch (flapState) {
    case FLAP_CLOSED: digitalWrite(PIN_STATUS, HIGH); break;
    case FLAP_OPEN:   digitalWrite(PIN_STATUS, LOW);  break;
    case FLAP_MOVING: digitalWrite(PIN_STATUS, (t / 400) & 1); break;
    case FLAP_FAULT:  digitalWrite(PIN_STATUS, (t / 100) & 1); break;
    default:          digitalWrite(PIN_STATUS, (t / 900) & 1); break;
  }
}

// ===========================================================================
// Button: short press toggles and takes manual control.
//         hold 2 s clears a fault and hands control back to the ASIAIR.
// ===========================================================================
void serviceButton() {
  bool down = (digitalRead(PIN_BUTTON) == LOW);
  unsigned long now = millis();

  if (down && !buttonWasDown) {
    buttonDownMs = now;
  } else if (down && buttonWasDown) {
    if (now - buttonDownMs > FAULT_CLEAR_HOLD_MS && flapState == FLAP_FAULT) {
      Serial.println("[BTN] fault cleared by hold");
      flapState = FLAP_UNKNOWN;
      faultReason = "";
      manualOverride = false;
      settled = false;             // re-settle before trusting the ASIAIR
      settleSinceMs = now;
      buttonDownMs = now + 3600000UL;   // don't retrigger on this press
    }
  } else if (!down && buttonWasDown) {
    unsigned long held = now - buttonDownMs;
    if (held > BUTTON_DEBOUNCE_MS && held < FAULT_CLEAR_HOLD_MS &&
        flapState != FLAP_FAULT) {
      manualOverride   = true;
      manualWantClosed = !(flapState == FLAP_CLOSED);
      Serial.printf("[BTN] manual -> %s\n", manualWantClosed ? "CLOSED" : "OPEN");
      beginMove(manualWantClosed);
    }
  }
  buttonWasDown = down;
}

// ===========================================================================
void setup() {
  Serial.begin(115200);
  delay(200);
  Serial.println("\nRedCat 51 II flat panel - Rev C");

  pinMode(PIN_OPEN_LIMIT,   INPUT_PULLUP);
  pinMode(PIN_CLOSED_LIMIT, INPUT_PULLUP);
  pinMode(PIN_BUTTON,       INPUT_PULLUP);
  pinMode(PIN_STATUS,       OUTPUT);
  digitalWrite(PIN_STATUS, LOW);

  // ADC1_CH3 on GPIO4. 12 dB attenuation -> ~0-3.1 V usable.
  analogSetPinAttenuation(PIN_ASIAIR, ADC_11db);
  analogReadResolution(12);

  ledcAttach(PIN_LED, LED_PWM_HZ, LED_PWM_BITS);
  ledcWrite(PIN_LED, 0);

  bootMs        = millis();
  settleSinceMs = bootMs;
  settleRefV    = readPortVolts();

  // Do NOT move on boot. Rev B blindly drove to OPEN in setup(), which slams
  // the flap against its stop before anyone has checked the mechanism, and
  // does it every time the ASIAIR's own 12 V rail browns out on mount slew.
  // Instead, adopt whatever state the limit switches say we are already in.
  if (limitAsserted(PIN_CLOSED_LIMIT))    flapState = FLAP_CLOSED;
  else if (limitAsserted(PIN_OPEN_LIMIT)) flapState = FLAP_OPEN;
  else                                    flapState = FLAP_UNKNOWN;
  Serial.printf("[BOOT] flap is %s\n",
                flapState == FLAP_CLOSED ? "CLOSED" :
                flapState == FLAP_OPEN   ? "OPEN" : "UNKNOWN (between stops)");
}

void loop() {
  serviceButton();
  serviceMove();
  serviceStatusLed();

  if (millis() - lastSampleMs < SAMPLE_INTERVAL_MS) return;
  lastSampleMs = millis();

  float v = readPortVolts();

  // --- ASIAIR boot transient guard -------------------------------------
  // All ASIAIR power ports come up at FULL for a few seconds before the saved
  // per-port settings are applied. Refuse to act on the input until it has
  // held still for SETTLE_MS.
  if (!settled) {
    if (fabsf(v - settleRefV) > 0.6f) {
      settleRefV    = v;
      settleSinceMs = millis();
    } else if (millis() - settleSinceMs > SETTLE_MS) {
      settled     = true;
      lastCommand = classify(v, CMD_OPEN);
      Serial.printf("[SETTLE] port stable at %.2f V, taking control\n", v);
    }
    return;
  }

  Command cmd = classify(v, lastCommand);

  if (cmd != lastCommand) {
    Serial.printf("[ASIAIR] %.2f V -> %s\n", v,
                  cmd == CMD_OPEN ? "OPEN" : cmd == CMD_COVER ? "COVER" : "LIGHT");
    // any deliberate ASIAIR change takes control back from the button
    manualOverride = false;
    lastCommand = cmd;
  }

  if (flapState == FLAP_FAULT || manualOverride) return;

  switch (cmd) {
    case CMD_OPEN:
      setLed(0.0f);
      if (flapState != FLAP_OPEN && !moveActive) beginMove(false);
      break;
    case CMD_COVER:
      setLed(0.0f);
      if (flapState != FLAP_CLOSED && !moveActive) beginMove(true);
      break;
    case CMD_LIGHT:
      if (flapState != FLAP_CLOSED) {
        if (!moveActive) beginMove(true);   // setLed() refuses until confirmed
      } else {
        setLed(brightnessFor(v));
      }
      break;
  }
}

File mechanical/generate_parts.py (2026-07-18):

"""
RedCat 51 II automated flat panel - Revision C mechanical source.

WHAT CHANGED FROM REV B (and why)
---------------------------------
Rev B built every part in its own private coordinate system and never assembled
them.  That is how the following escaped:

  * the enclosure box was built centred on z=0 but every cut-out was placed as if
    the floor were z=0, putting the connector openings ~14 mm too high and
    breaching the top rim;
  * the four PCB standoffs were extruded z=0..7 while the cavity floor sat at
    z=-11.5, so they floated in mid-air (the STL contained 5 disconnected bodies);
  * the tray pivot was placed 72 mm from the optical axis on the assumption that
    the servo output shaft sits at the centre of the servo body.  It does not -
    a standard 40 mm-body servo has its shaft offset ~10 mm from body centre, so
    the closed panel would have sat 7-13 mm off-axis;
  * the servo platform met the clamp with a ~1 mm deep sliver of overlap and no
    gussets or fillets anywhere.

Rev C builds every part in ONE shared scope coordinate frame, asserts the
clearances numerically, and exports an assembly STEP so the next mistake of this
class is visible instead of latent.

COORDINATE FRAME (scope frame)
------------------------------
    origin  = on the optical axis, at the REAR face of the clamp
    +Z      = along the optical axis, toward the sky
    -X      = toward the servo (the 9 o'clock position, viewed from the front)

    Z=0      clamp rear face
    Z=17..25 servo shelf (integral with clamp, carried on two full-depth webs)
    Z=25..29 servo plate (separate part - isolates the shaft-offset unknown)
    Z=30     clamp front face ~ dew shield front lip
    Z=35     servo top face  -> horn at Z=35..38
    Z=35.8   tray rear face  (= 3 mm of clearance in front of the shield rim,
                              plus the 2.8 mm retaining ring at Z=33..35.8)
    Z=38..43 tray arm / hub  (bolts to the horn)

PARTS ARE MODELLED in this frame and exported to STL in a PRINT frame (flat, no
support).  The assembly STEP is exported in the scope frame.

>>> MEASURE THESE FOUR NUMBERS BEFORE PRINTING ANYTHING EXPENSIVE <<<
Everything else is derived.  Each has a cheap coupon to check it against.
"""

from pathlib import Path
import math
import cadquery as cq
from cadquery import exporters

HERE = Path(__file__).resolve().parent
OUT = HERE

# ============================================================================
# MEASURED PARAMETERS  - the only numbers you should ever need to touch
# ============================================================================

# 1. Dew shield outside diameter.  Check with 01-diameter-fit-gauge.
#    William Optics quote the RedCat 51 II as 228 x 80 mm "with the retracted
#    dew shield", so 80.0 is a *plausible* default - it is not a measurement.
SCOPE_DIAMETER = 80.0

# 2. Servo output shaft offset from the centre of the servo body, along the
#    body's long axis.  ~10 mm on a standard 40 mm-body servo (DS3218/MG996R
#    class).  Check with 09-servo-shaft-gauge before printing the plate.
SERVO_SHAFT_OFFSET = 10.0

# 3. Distance from the servo's top face down to the underside of the mounting
#    ears.  Sets the horn height, and therefore the tray height.
SERVO_EAR_TO_TOP = 10.0

# 4. Barrel jack axis height above the PCB top surface.  The PJ-102AH drawing
#    gives body 14.4 x 11.0 x 9.0 mm and a 6.5 mm nose, but does not label the
#    axis height unambiguously, and KiCad ships this footprint's 3D model as
#    VRML only - so it is absent from the board STEP and cannot be measured.
#    The Rev C opening is deliberately oversized (see DC_JACK_OPENING_D) so this
#    number does not have to be exactly right.  Check with 10-connector-coupon.
DC_JACK_AXIS_Z = 4.7

# ============================================================================
# DERIVED / FIXED PARAMETERS
# ============================================================================

LINER_THICKNESS = 0.8
FIT_CLEARANCE = 0.5
CLAMP_ID = SCOPE_DIAMETER + 2 * LINER_THICKNESS + FIT_CLEARANCE   # 82.1
CLAMP_WALL = 6.0
CLAMP_OD = CLAMP_ID + 2 * CLAMP_WALL                              # 94.1
CLAMP_R = CLAMP_OD / 2                                            # 47.05
CLAMP_H = 30.0            # was 24 in Rev B - more grip, more web height

# Servo envelope (standard 40 mm "20 kg" servo: DS3218, MG996R, ...)
SERVO_BODY_L = 40.0
SERVO_BODY_W = 20.0
SERVO_BODY_H = 40.5
SERVO_HOLE_DX = 49.5      # Rev B used 49.0; the standard is 49.5
SERVO_HOLE_DY = 10.0

# Pivot: optical axis -> servo output shaft.
# Lower bound is set by the servo body clearing the clamp; upper bound by the
# swing envelope.  check_clearances() proves the choice.
PIVOT_R = 72.0

# Z stack
SHELF_Z0, SHELF_Z1 = 17.0, 25.0
PLATE_T = 4.0
PLATE_Z0 = SHELF_Z1                       # 25
PLATE_Z1 = PLATE_Z0 + PLATE_T             # 29
SERVO_TOP_Z = PLATE_Z1 + SERVO_EAR_TO_TOP # 39  (ears rest on the plate top)
HORN_T = 3.0
ARM_T = 5.0
ARM_Z0 = SERVO_TOP_Z + HORN_T             # 42
ARM_Z1 = ARM_Z0 + ARM_T                   # 47

# Tray / panel
TRAY_OD = 104.0
TRAY_R = TRAY_OD / 2
RECESS_D = 82.4
TRAY_T = 14.0
FLOOR_T = 3.0
RETAINER_T = 2.8
RETAINER_ID = 74.0
PANEL_CLEARANCE = 3.0                     # closed diffuser -> dew shield rim
RETAINER_Z0 = CLAMP_H + PANEL_CLEARANCE   # 33.0
TRAY_Z0 = RETAINER_Z0 + RETAINER_T        # 35.8  (tray rear face)
TRAY_Z1 = TRAY_Z0 + TRAY_T                # 49.8

# Motion
OPEN_ANGLE_DEG = 104.0

# Enclosure / PCB
PCB_X, PCB_Y, PCB_T = 120.0, 75.0, 1.6
PCB_HOLES = [(40, 4), (116, 4), (40, 71), (116, 71)]   # board coords
STANDOFF_H = 6.0
STANDOFF_OD = 7.6
STANDOFF_PILOT = 2.7                      # M3 thread-forming pilot
WALL = 2.6
FLOOR = 3.0
BOX_CLEAR_X, BOX_CLEAR_Y = 5.0, 5.0
BOX_IN_X = PCB_X + BOX_CLEAR_X
BOX_IN_Y = PCB_Y + BOX_CLEAR_Y
BOX_OUT_X = BOX_IN_X + 2 * WALL
BOX_OUT_Y = BOX_IN_Y + 2 * WALL
BOX_H = 30.0
DC_JACK_OPENING_D = 10.0   # Ø6.5 nose + the plug's moulded body + tolerance on
                           # DC_JACK_AXIS_Z.  Deliberately generous.
MAX_COMPONENT_H = 10.5     # C2/C7 470uF cans, measured from the board STEP

# Lid fixing.  Rev B's lid was a friction fit with pull lugs.  This box lives
# outdoors, upside down, in dew, on a moving mount - it gets screws.  The bosses
# sit on the OUTER corners so they cost no internal volume and cannot foul the
# board; check_clearances() proves the PCB corner clears them.
BOSS_R = 4.5
BOSS_INSET = 0.6           # boss centre, inboard of the outer corner
BOSS_CX = BOX_OUT_X / 2 - BOSS_INSET
BOSS_CY = BOX_OUT_Y / 2 - BOSS_INSET
LID_T = 3.0

# Strap slots.  The box hangs off the dovetail bar or a tripod leg with a
# hook-and-loop strap - NOT off the dew shield, which is a slip joint that will
# happily let go of an 80 mm tube.
STRAP_W = 25.0
STRAP_T = 3.2

M3_INSERT_D = 4.2
M3_INSERT_L = 5.5
M3_CLEAR = 3.4
M4_CLEAR = 4.4

_warnings = []
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

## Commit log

2026-07-17 Initial RedCat 51 II automated flat panel release
    [01-diameter-fit-gauge.step, 01-diameter-fit-gauge.stl, 02-scope-clamp.step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]
2026-07-18 Replace Rev B with Rev C: corrected, self-checking design
    Removes the Rev B release (planeless board, un-compilable-premise firmware,
    un-assembled mechanicals) and replaces it with Rev C.
    Mechanical (verified): every part built in one shared scope frame; 19 numeric
    clearance assertions; all 10 STLs single-body and watertight; fixes floating
    standoffs, connector openings 14 mm too high, and the off-axis pivot; adds a
    screwed lid and strap ears.
    Firmware (reviewed, not compiled): ADC average-voltage ASIAIR sensing instead
    of duty-sniffing (which cannot work on a filtered ASIAIR Plus); latching fault
    after bounded retries instead of the infinite stall-cook loop; non-blocking
    state machine; bo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
    [00-ASSEMBLY.step, 01-diameter-fit-gauge.step, 01-diameter-fit-gauge.stl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]
2026-07-18 Add AGPL-3.0 license
    License the whole project (mechanical, firmware, PCB, docs) under AGPL-3.0-or-later so forks and derivatives stay open. Adds LICENSE and a License section in the README.
